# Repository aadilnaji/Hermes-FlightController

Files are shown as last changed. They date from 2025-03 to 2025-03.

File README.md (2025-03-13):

# **Hermes Flight Controller**

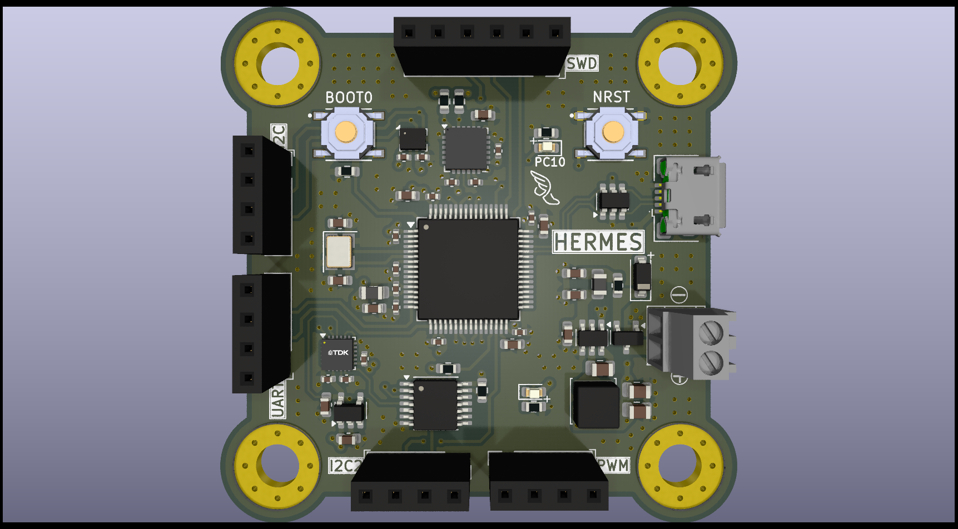
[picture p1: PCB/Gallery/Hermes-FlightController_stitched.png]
Project Banner


## **Overview**
This is a **custom STM32F405 based Flight Controller** designed for drone applications. The PCB is designed in **KiCad**.

Design is done and now it's onto fabricating the PCB and writing the firmware.
Check back for updates.

## **Features**
- **Microcontroller:** STM32F405RGT6
- **IMU Sensor:** MPU-6050 / ICM-2098
- **Barometer:** BMP280
- **ESC Outputs:** 4x PWM channels
- **Communication Interfaces:** UART, I2C, USB

## **Hardware Design**
### **Schematic & PCB Layout**
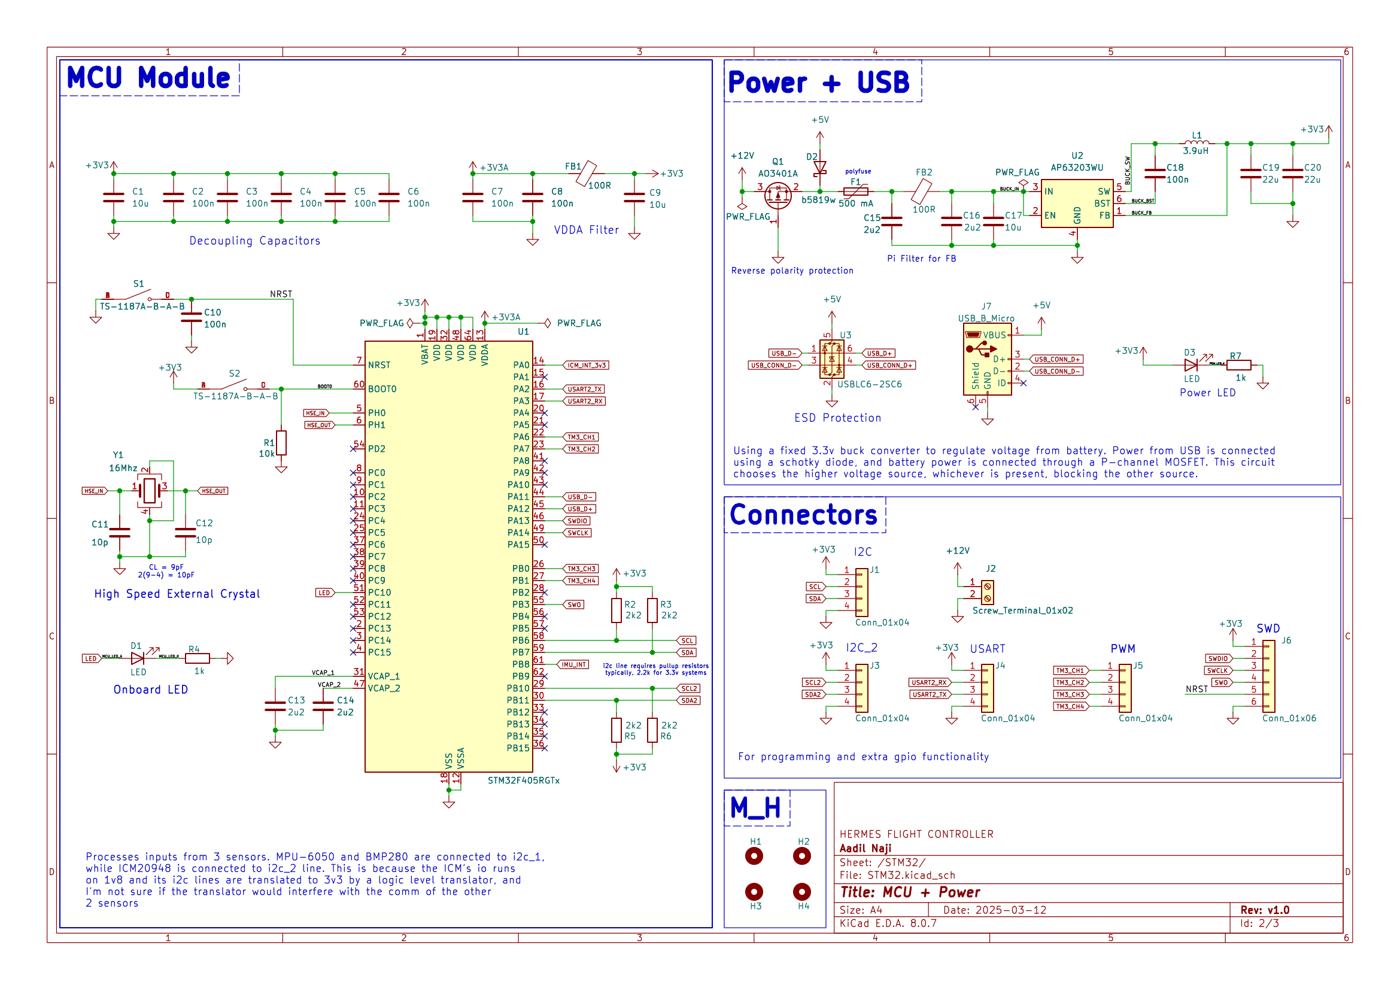
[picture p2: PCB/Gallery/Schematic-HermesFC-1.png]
Schematic1

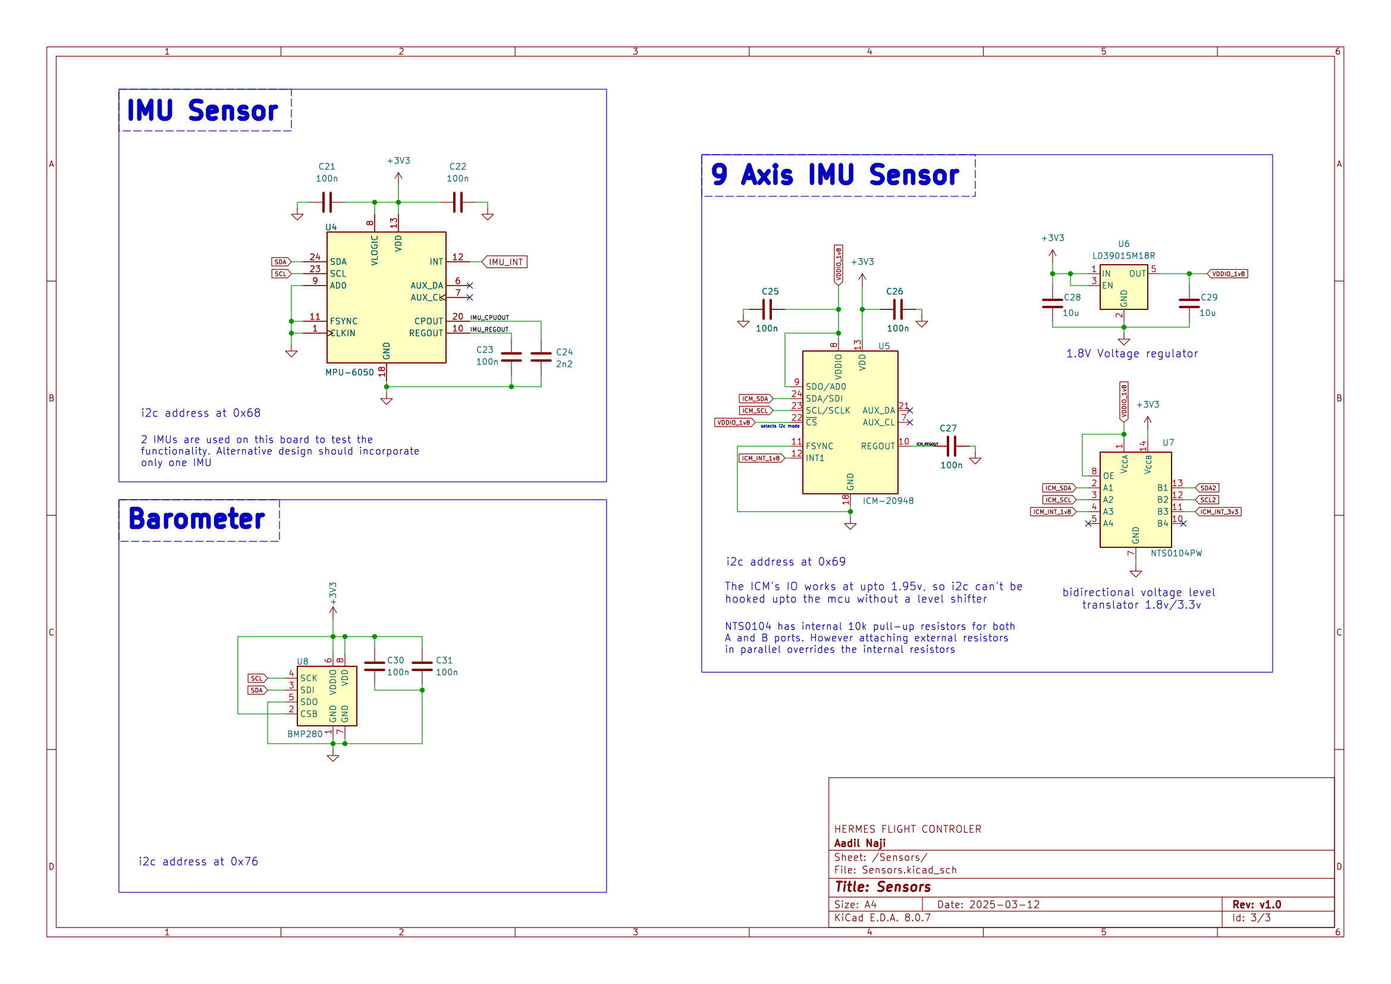
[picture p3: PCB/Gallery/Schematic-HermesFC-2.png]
Schematic2

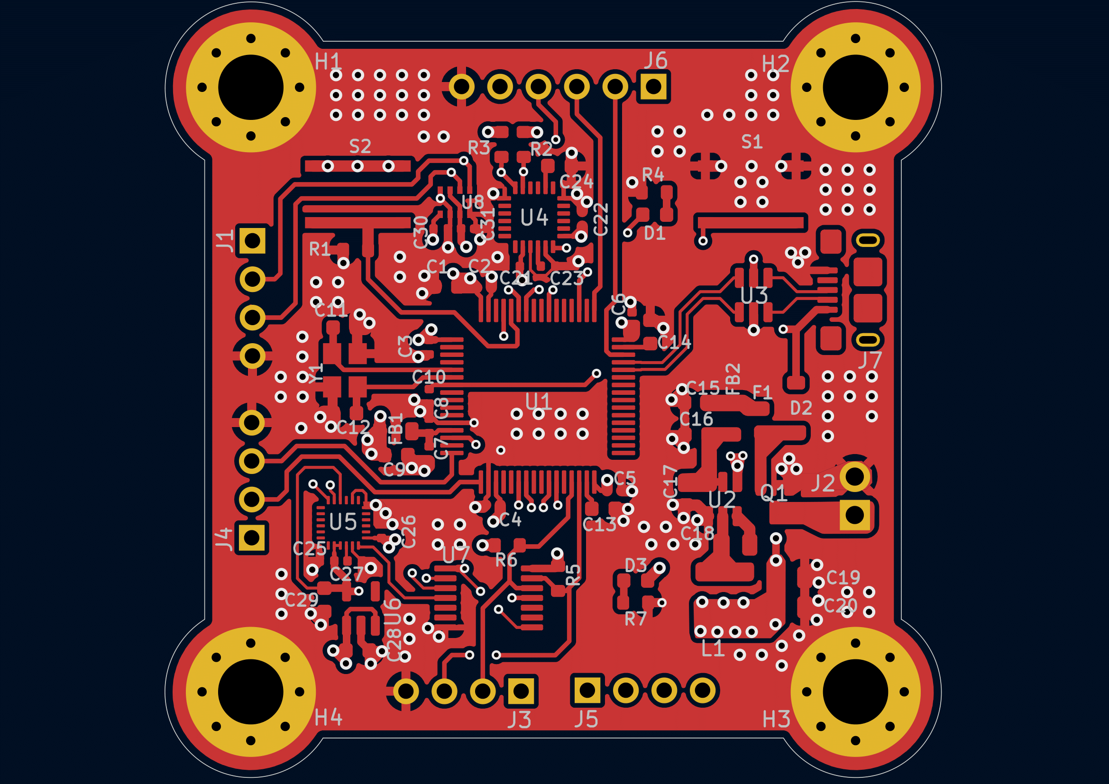
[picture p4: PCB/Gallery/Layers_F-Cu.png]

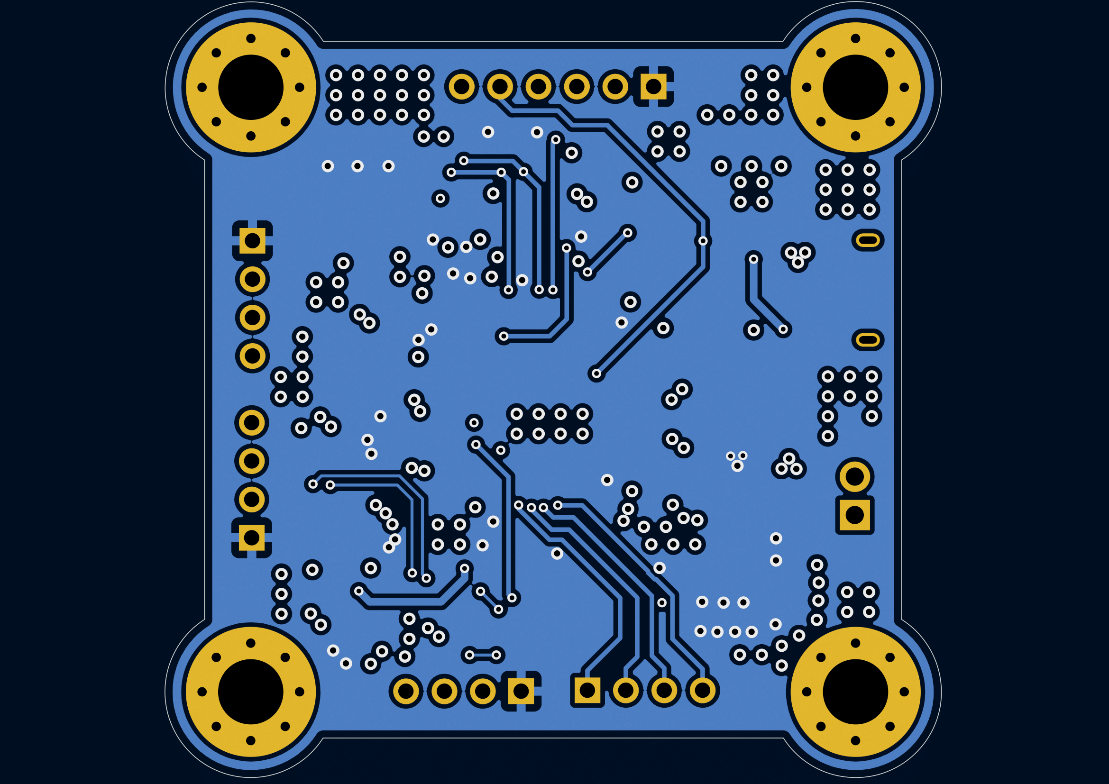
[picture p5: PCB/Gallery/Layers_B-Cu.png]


## **License**
This project is open-source under the **MIT License**.

---
🚀 **Happy Flying!**

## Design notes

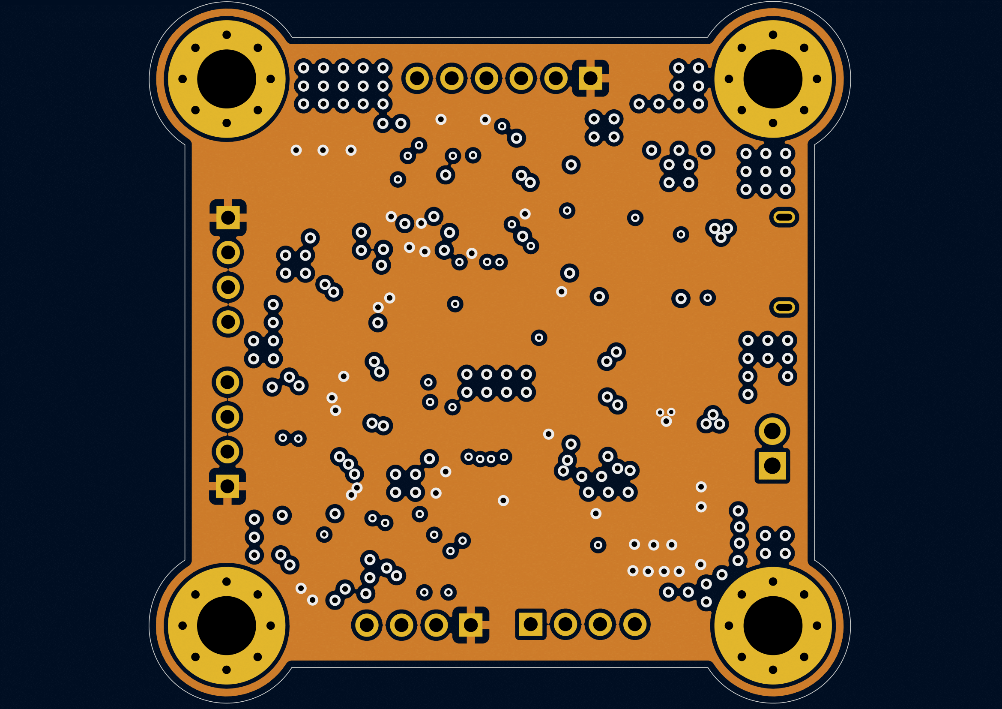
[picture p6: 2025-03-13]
PCB/Gallery/Layers_ln2.png

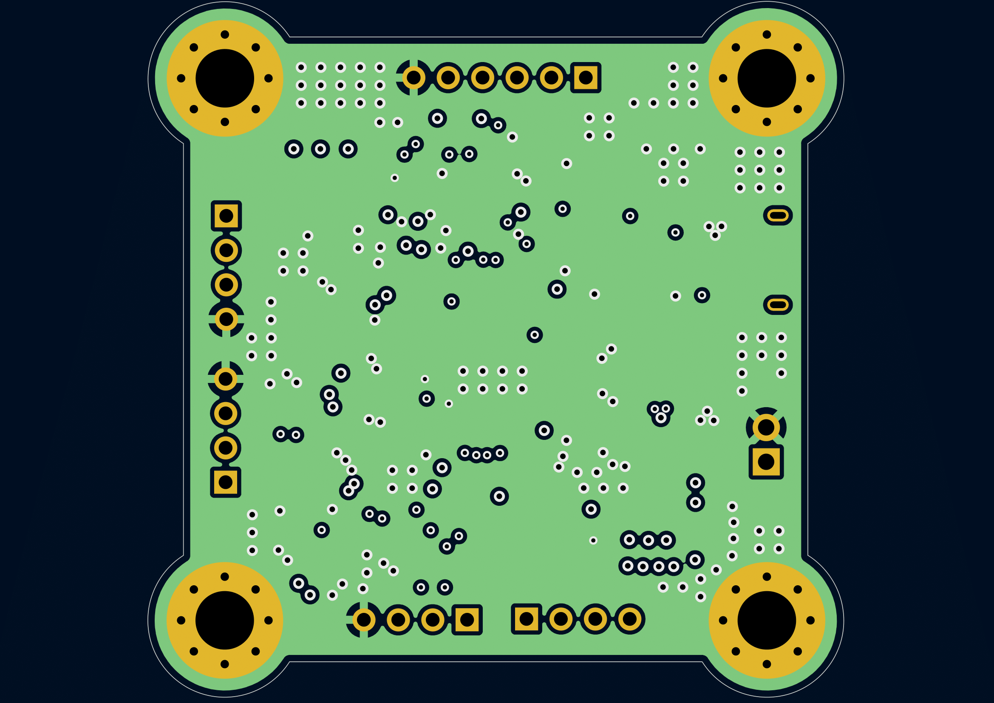
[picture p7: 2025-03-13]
PCB/Gallery/Layers_ln1.png

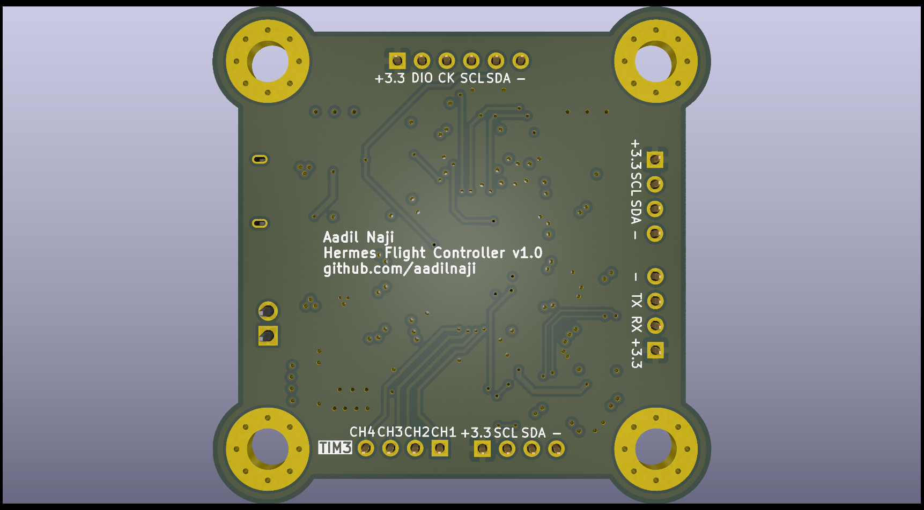
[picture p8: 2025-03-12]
PCB/Gallery/Hermes-FlightController_back.png

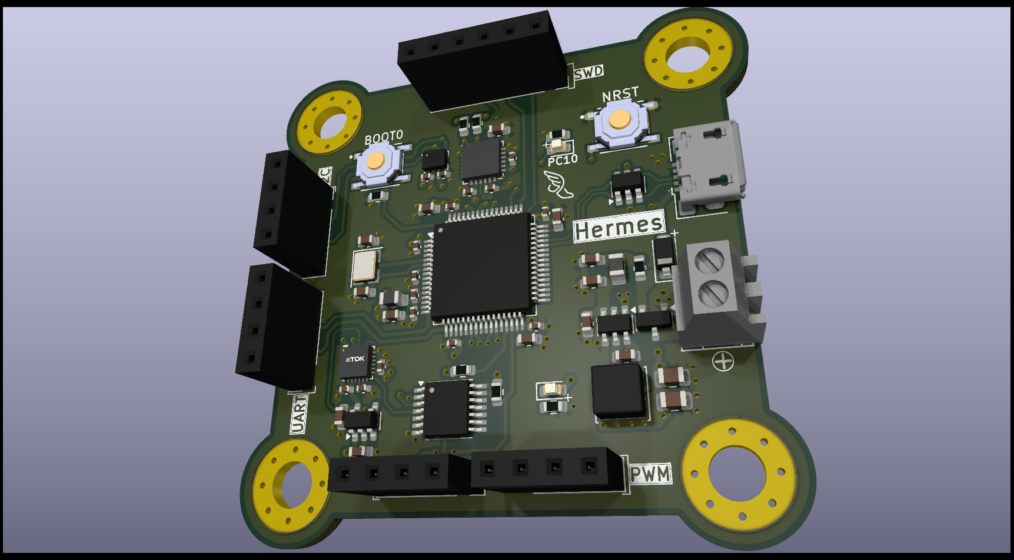
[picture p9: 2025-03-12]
PCB/Gallery/HermesFC_iso.png

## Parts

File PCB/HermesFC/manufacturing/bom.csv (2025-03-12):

Designator | Footprint | Quantity | Value | LCSC Part #
C1, C17, C28, C29, C9 | 603 | 5 | 10u | C96446
C10, C2, C21, C22, C23, C25, C26, C27, C3, C30, C31, C4, C5, C6, C7, C8 | 402 | 16 | 100n | C1525
C11, C12 | 603 | 2 | 10p | C1634
C13, C14, C15, C16 | 603 | 4 | 2u2 | C23630
C18 | 805 | 1 | 100n | C49678
C19, C20 | 805 | 2 | 22u | C45783
C24 | 603 | 1 | 2n2 | C1604
D1, D3 | 603 | 2 | LED | C2286
D2 | D_SOD-123 | 1 | b5819w | C8598
F1 | 603 | 1 | 500 mA | C20798
FB1, FB2 | 805 | 2 | 100R | C1015
L1 | L_Sunlord_SWPA4030S | 1 | 3.9uH | C96899
Q1 | SOT-23 | 1 | AO3401A | C15127
R1 | 603 | 1 | 10k | C25804
R2, R3, R5, R6 | 603 | 4 | 2k2 | C4190
R4, R7 | 603 | 2 | 1k | C21190
S1, S2 | SW_TS-1187A-B-A-B | 2 | TS-1187A-B-A-B | C318884
U1 | LQFP-64_10x10mm_P0.5mm | 1 | STM32F405RGTx | C15742
U2 | TSOT-23-6 | 1 | AP63203WU | C780769
U3 | SOT-23-6 | 1 | USBLC6-2SC6 | C7519
U4 | InvenSense_QFN-24_4x4mm_P0.5mm | 1 | MPU-6050 | C24112
U5 | InvenSense_QFN-24_3x3mm_P0.4mm | 1 | ICM-20948 | C726001
U6 | SOT-23-5 | 1 | LD39015M18R | C361025
U7 | TSSOP-14_4.4x5mm_P0.65mm | 1 | NTS0104PW | C2802637
U8 | Bosch_LGA-8_2x2.5mm_P0.65mm_ClockwisePinNumbering | 1 | BMP280 | C83291
Y1 | Crystal_SMD_3225-4Pin_3.2x2.5mm | 1 | 16Mhz | C13738

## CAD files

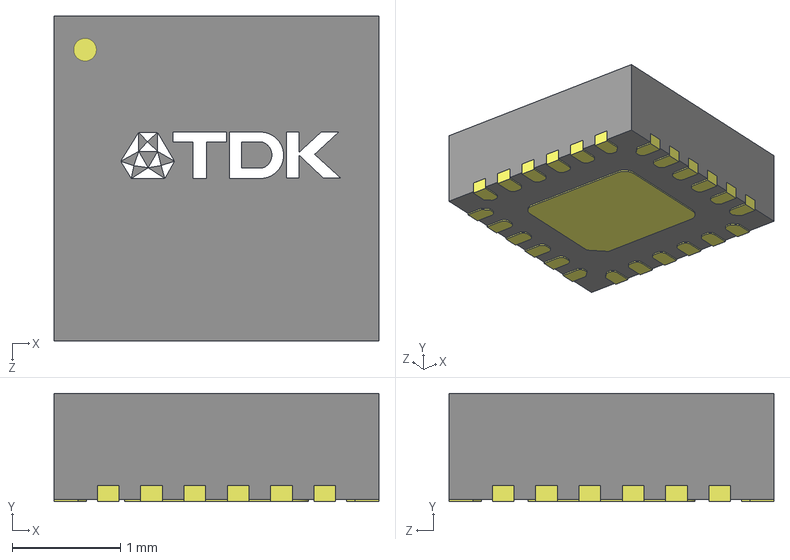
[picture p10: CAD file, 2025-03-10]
PCB/HermesFC/3Dmodels/ICM-20948.stp
3.00 x 1.00 x 3.00 mm

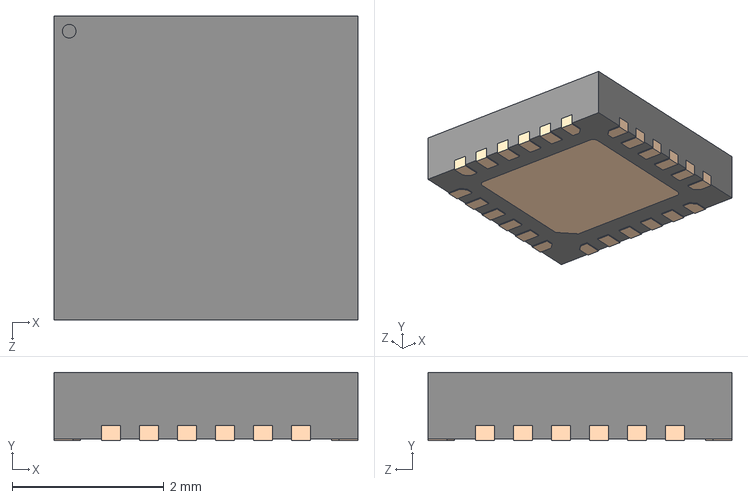
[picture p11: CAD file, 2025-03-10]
PCB/HermesFC/3Dmodels/MPU-6050.stp
4.00 x 0.9 x 4.00 mm

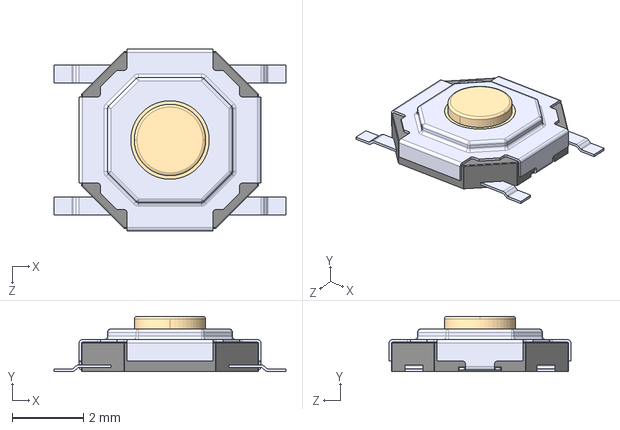
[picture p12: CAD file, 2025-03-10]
PCB/HermesFC/3Dmodels/TS-1187A-B-A-B.step
6.50 x 1.55 x 5.10 mm

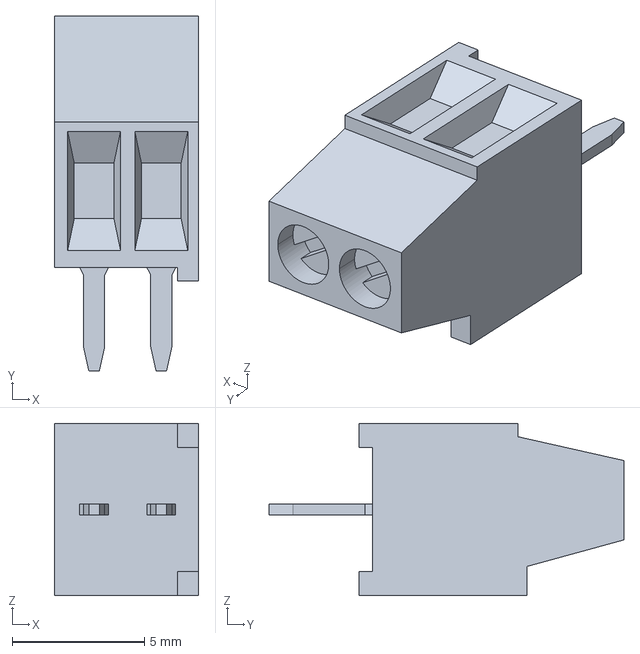
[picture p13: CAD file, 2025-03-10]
PCB/HermesFC/3Dmodels/screwT_2.54.stp
5.45 x 13.4 x 6.50 mm

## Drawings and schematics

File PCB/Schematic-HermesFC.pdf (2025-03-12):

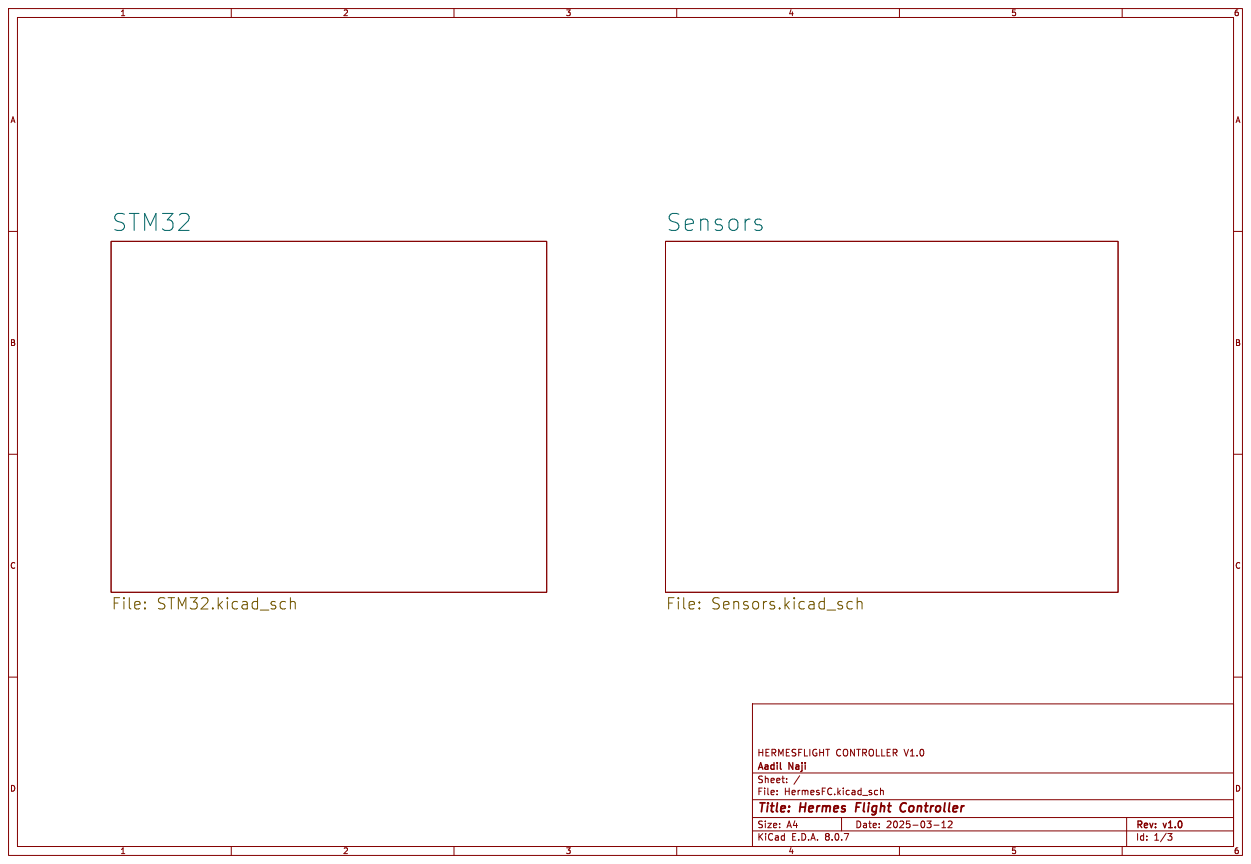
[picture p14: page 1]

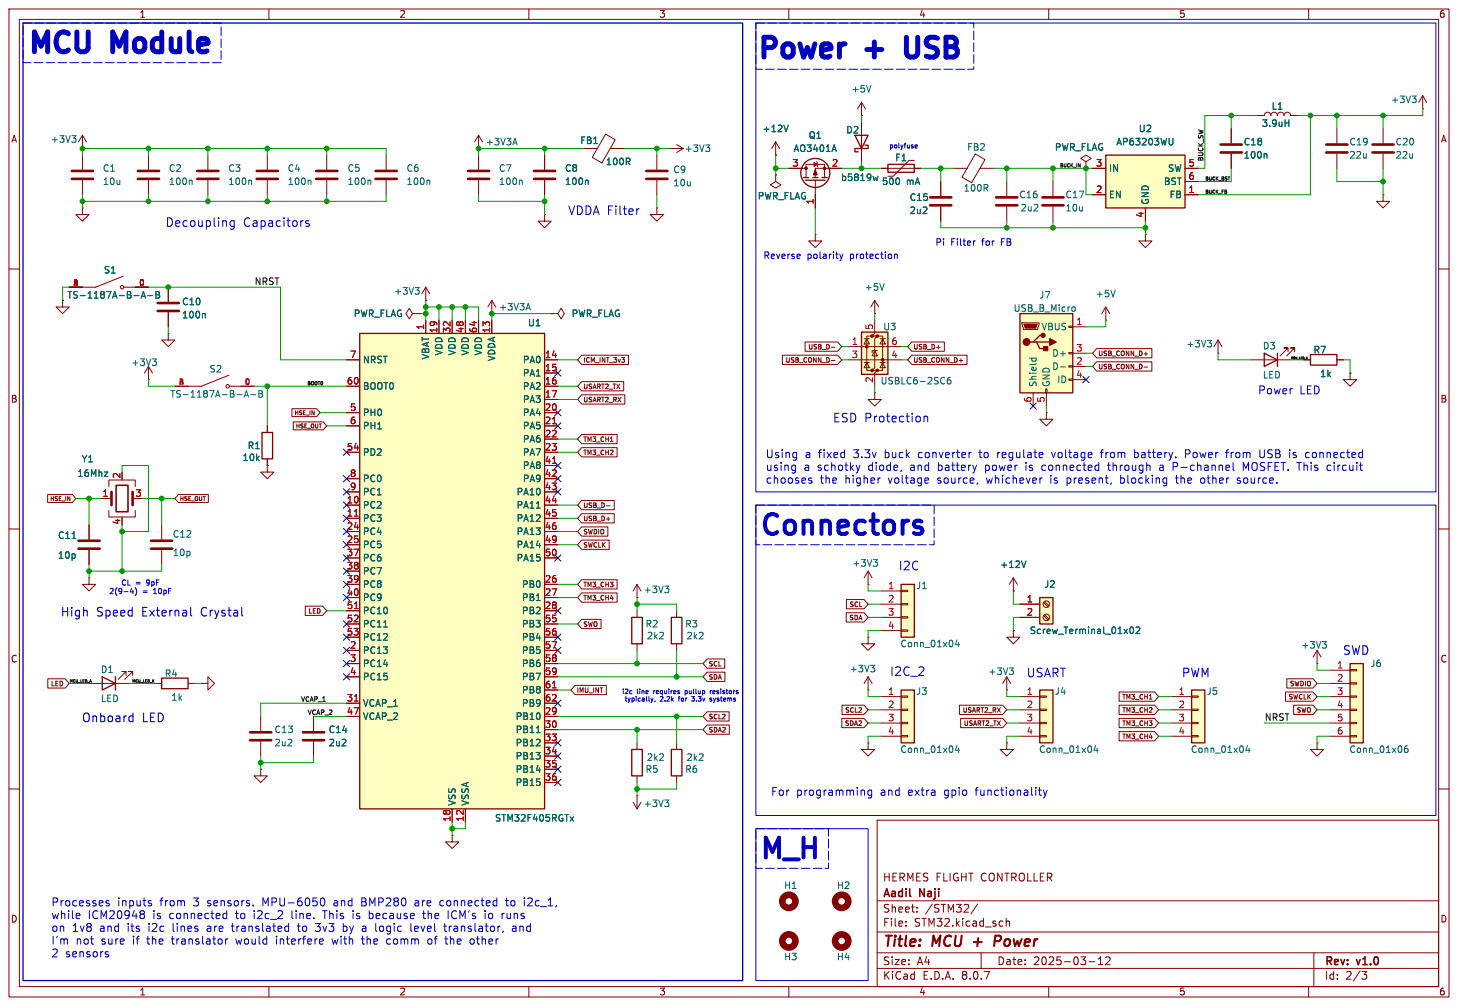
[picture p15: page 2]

1 PC2 10 PC3 11 VSSA 12 VDDA 13 PA0 14 PA1 15 PA2 16 PA3 17 VSS 18 VDD 19 PC13 2 PA4 20 PA5 21 PA6 22 PA7 23 PC4 24 PC5 25 PB0 26 PB1 27 PB2 28 PB10 29 PC14 3 PB11 30 VCAP_1 31 VDD 32 PB12 33 PB13 34 PB14 35 PB15 36 PC6 37 PC7 38 PC8 39 PC15 4 PC9 40 PA8 41 PA9 42 PA10 43 PA11 44 PA12 45 PA13 46 VCAP_2 47 VDD 48 PA14 49 PH0 5 PA15 50 PC10 51 PC11 52 PC12 53 PD2 54 PB3 55 PB4 56 PB5 57 PB6 58 PB7 59 PH1 6 BOOT0 60 PB8 61 PB9 62 VDD 64 NRST 7 PC0 8 PC1 9 C14

1 PC2 10 PC3 11 VSSA 12 VDDA 13 PA0 14 PA1 15 PA2 16 PA3 17 VSS 18 VDD 19 PC13 2 PA4 20 PA5 21 PA6 22 PA7 23 PC4 24 PC5 25 PB0 26 PB1 27 PB2 28 PB10 29 PC14 3 PB11 30 VCAP_1 31 VDD 32 PB12 33 PB13 34 PB14 35 PB15 36 PC6 37 PC7 38 PC8 39 PC15 4 PC9 40 PA8 41 PA9 42 PA10 43 PA11 44 PA12 45 PA13 46 VCAP_2 47 VDD 48 PA14 49 PH0 5 PA15 50 PC10 51 PC11 52 PC12 53 PD2 54 PB3 55 PB4 56 PB5 57 PB6 58 PB7 59 PH1 6 BOOT0 60 PB8 61 PB9 62 VDD 64 NRST 7 PC0 8 PC1 9 U1 STM32F405RGTx R6

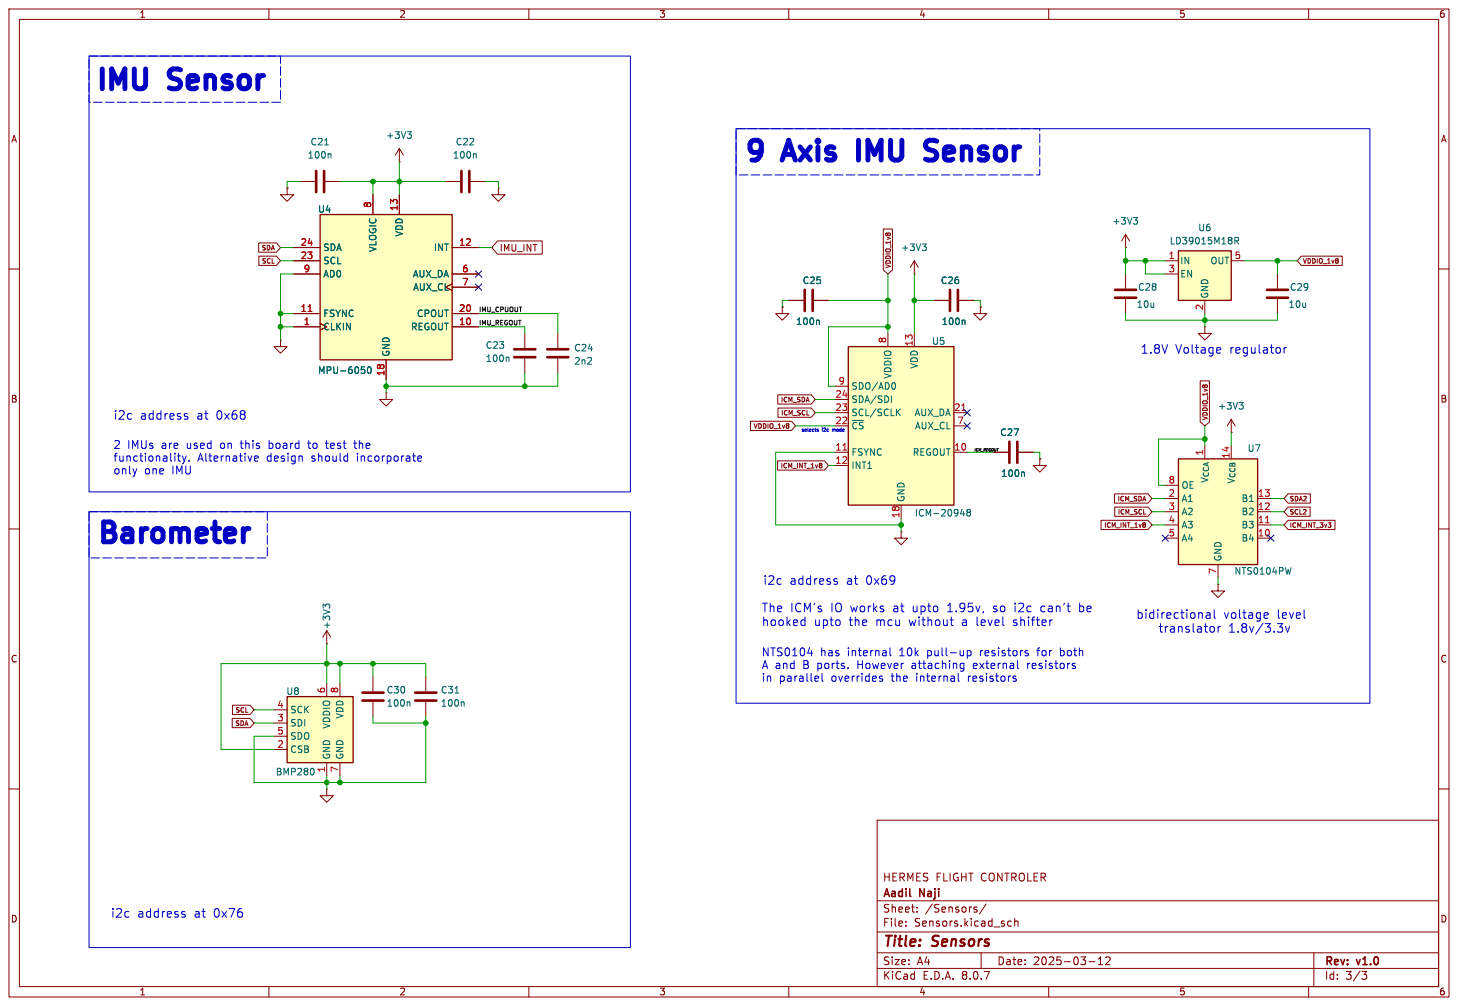
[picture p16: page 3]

2 IMUs are used on this board to test the
only one IMU
Barometer

The ICM's IO works at upto 1.95v, so i2c can't be

1 CSB 2 SDI 3 SCK 4 SDO 5 VDDIO

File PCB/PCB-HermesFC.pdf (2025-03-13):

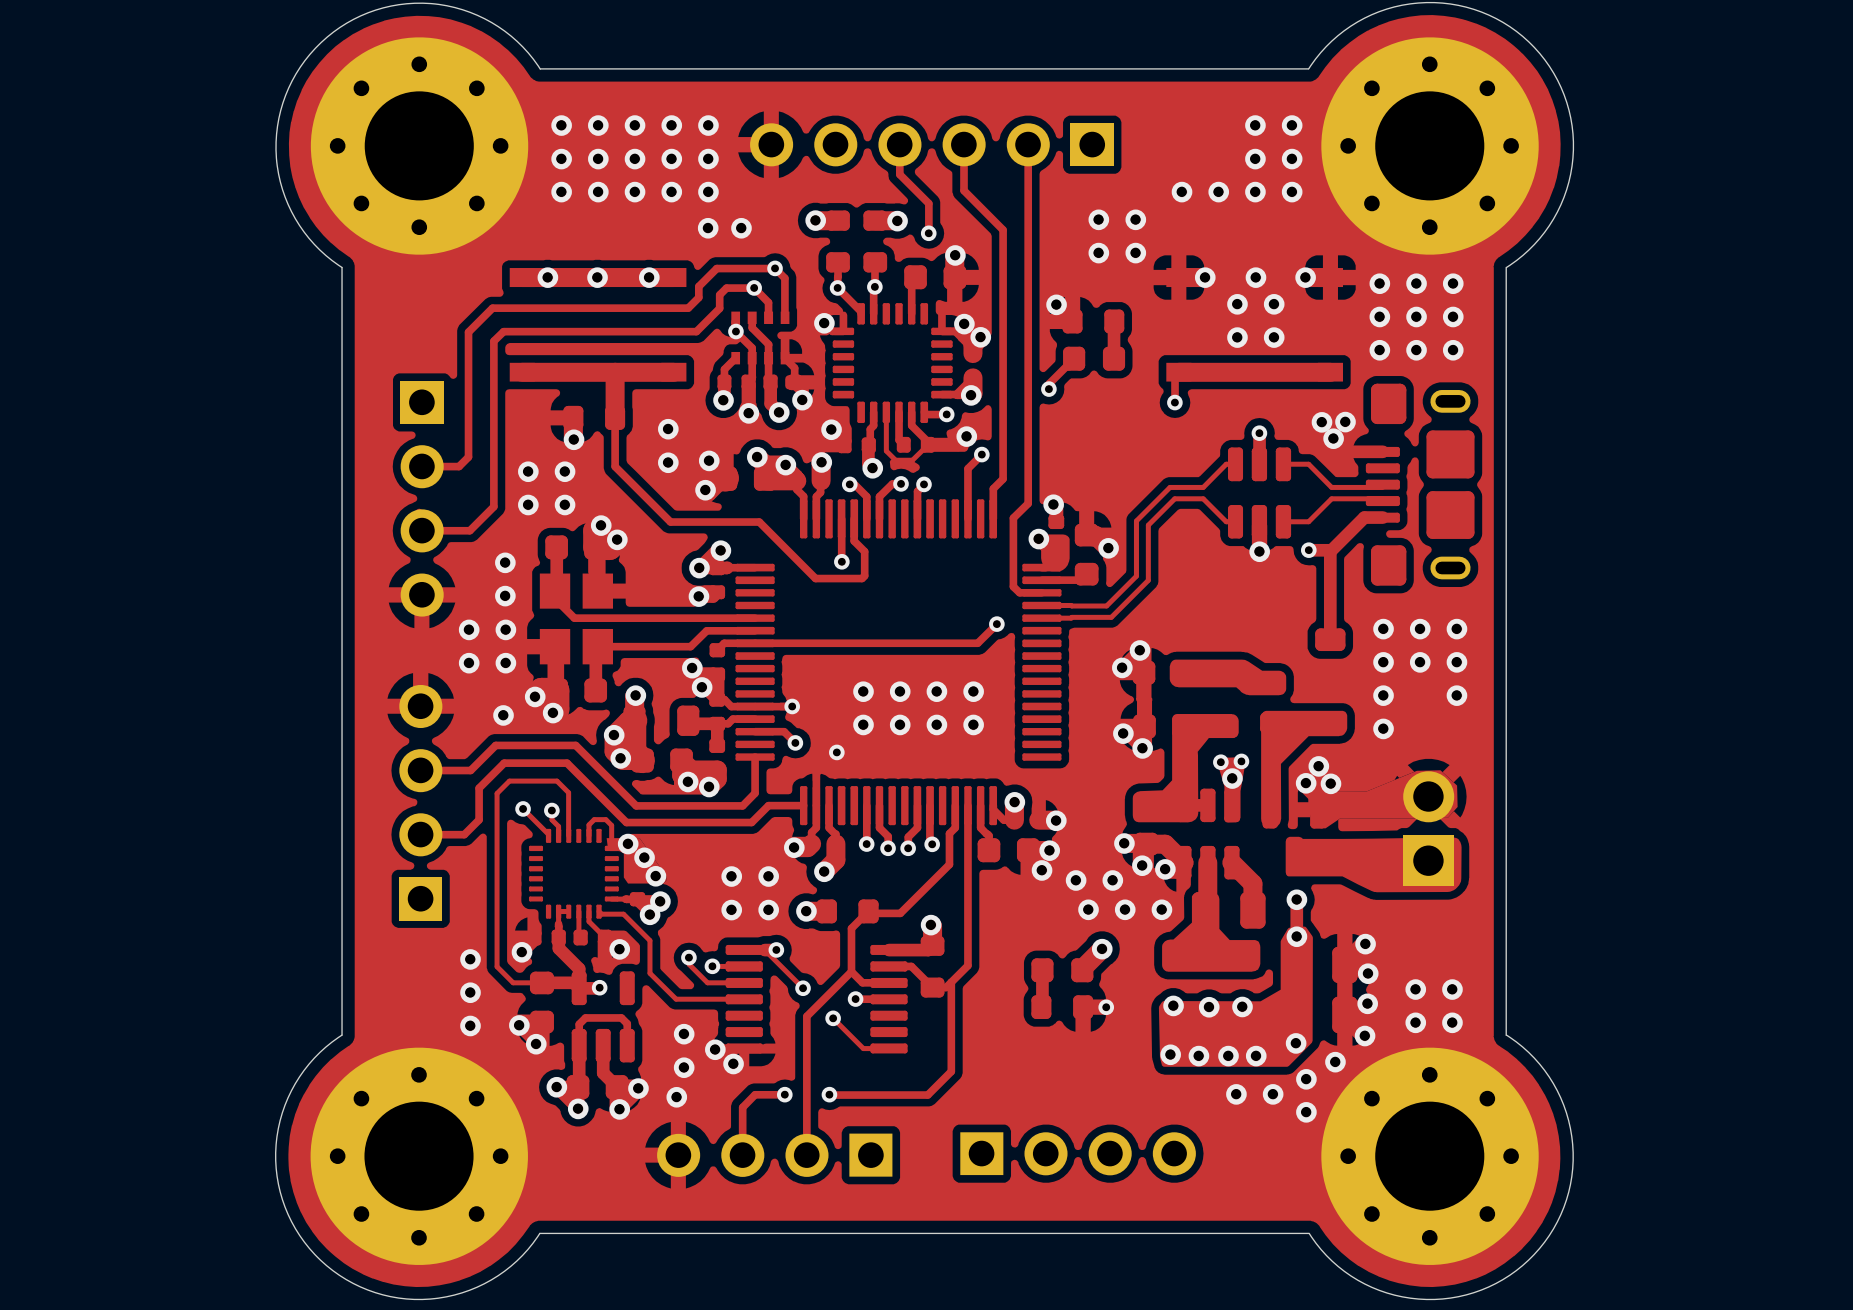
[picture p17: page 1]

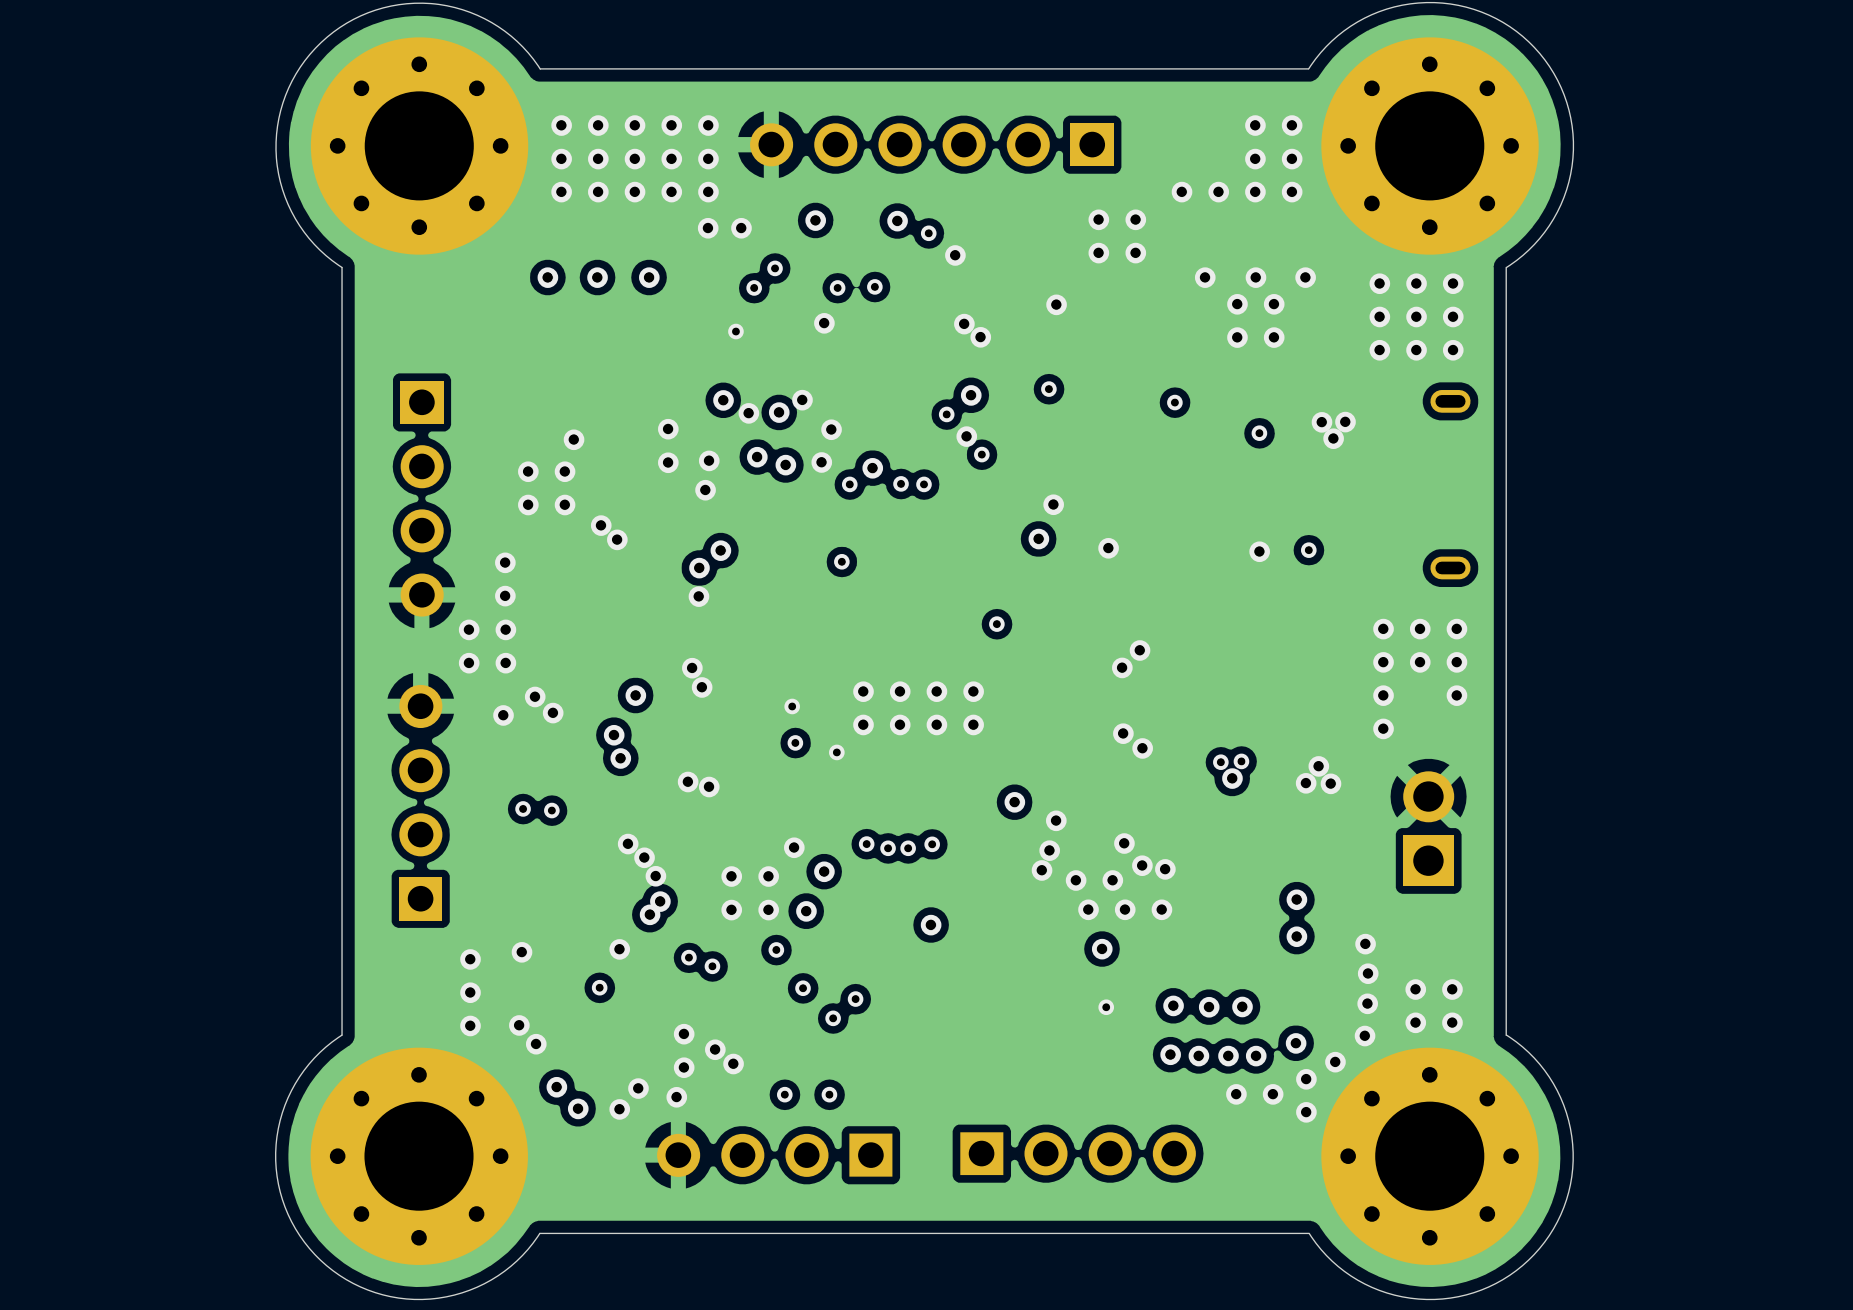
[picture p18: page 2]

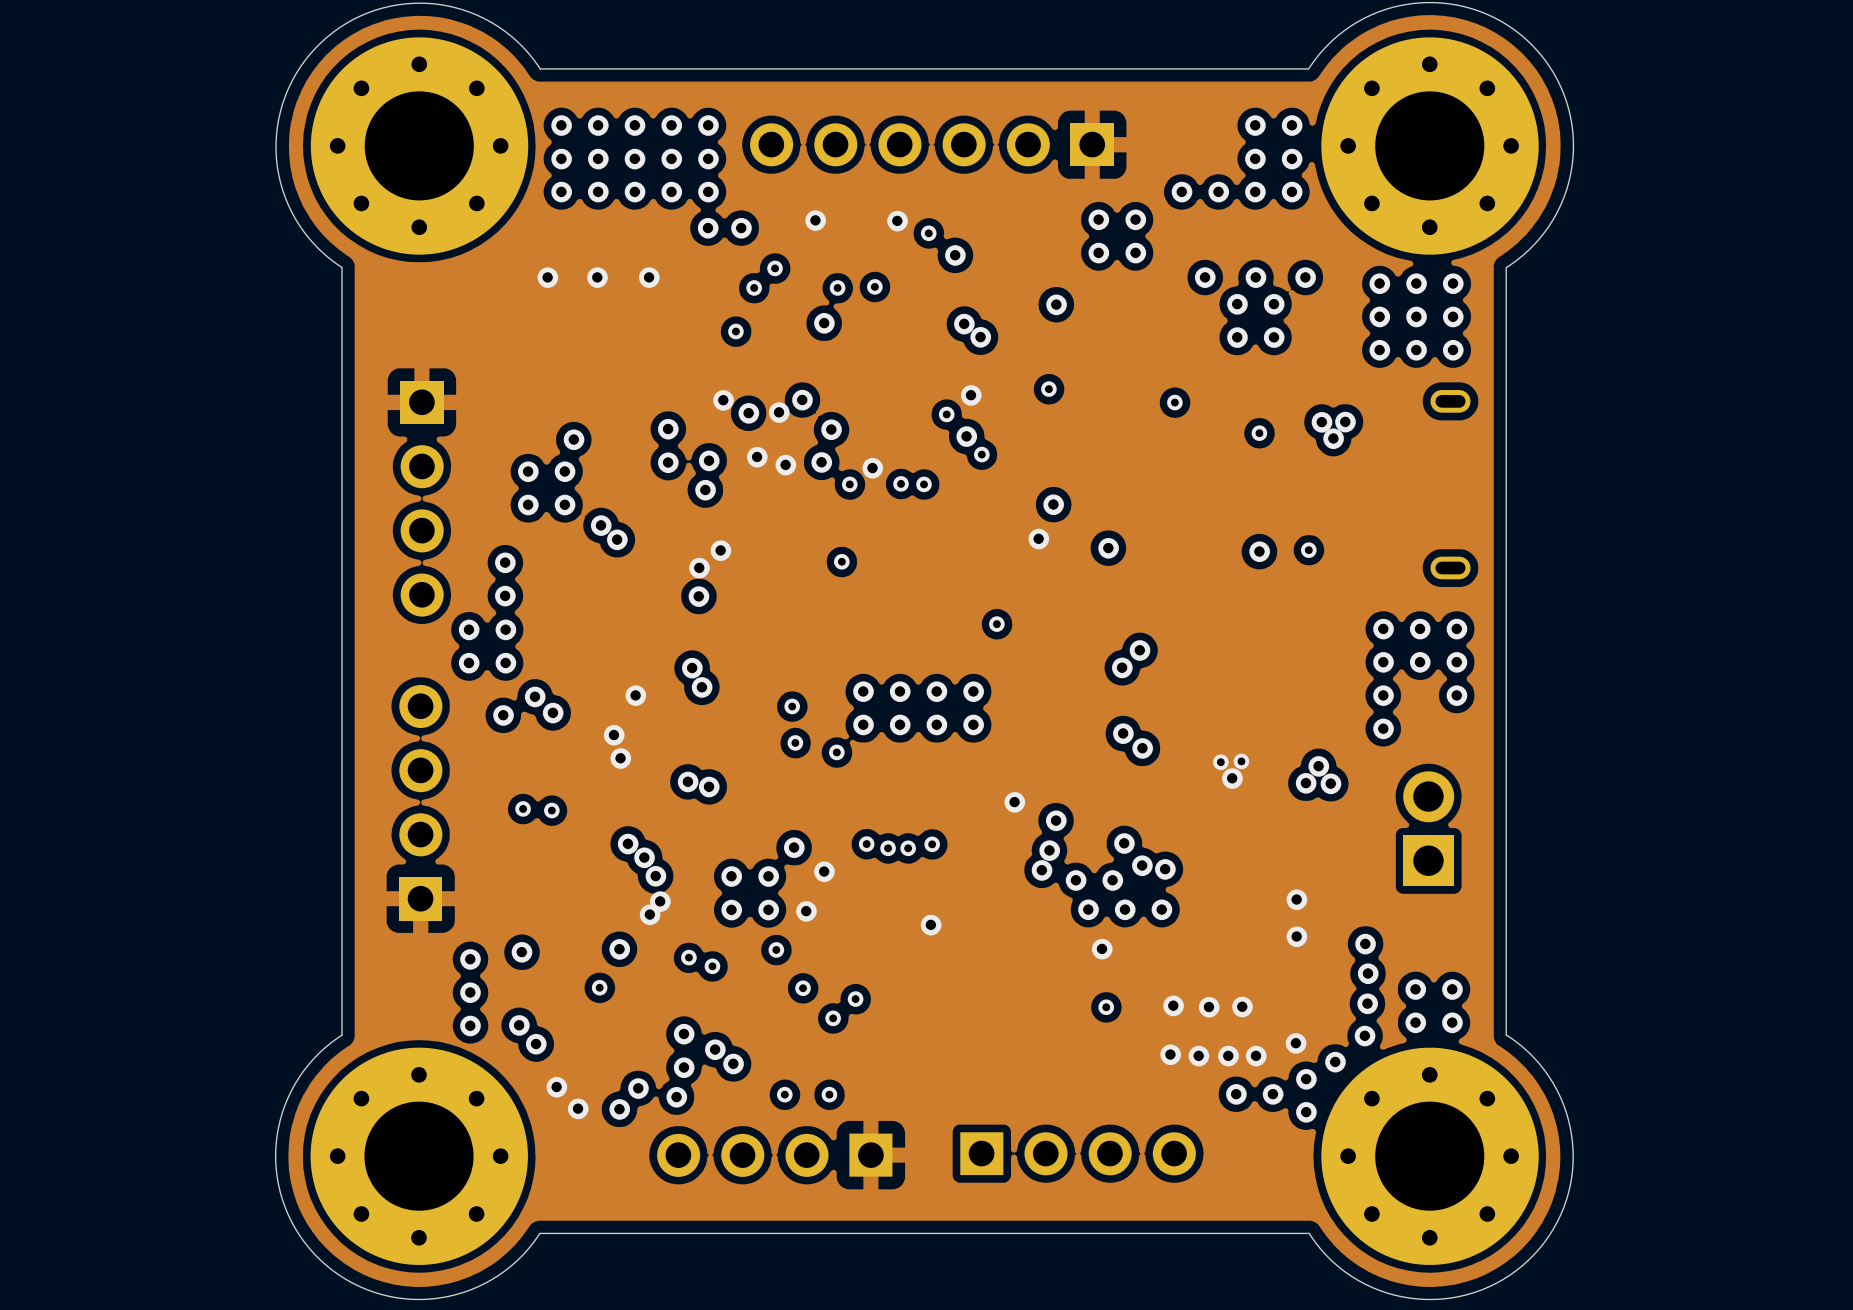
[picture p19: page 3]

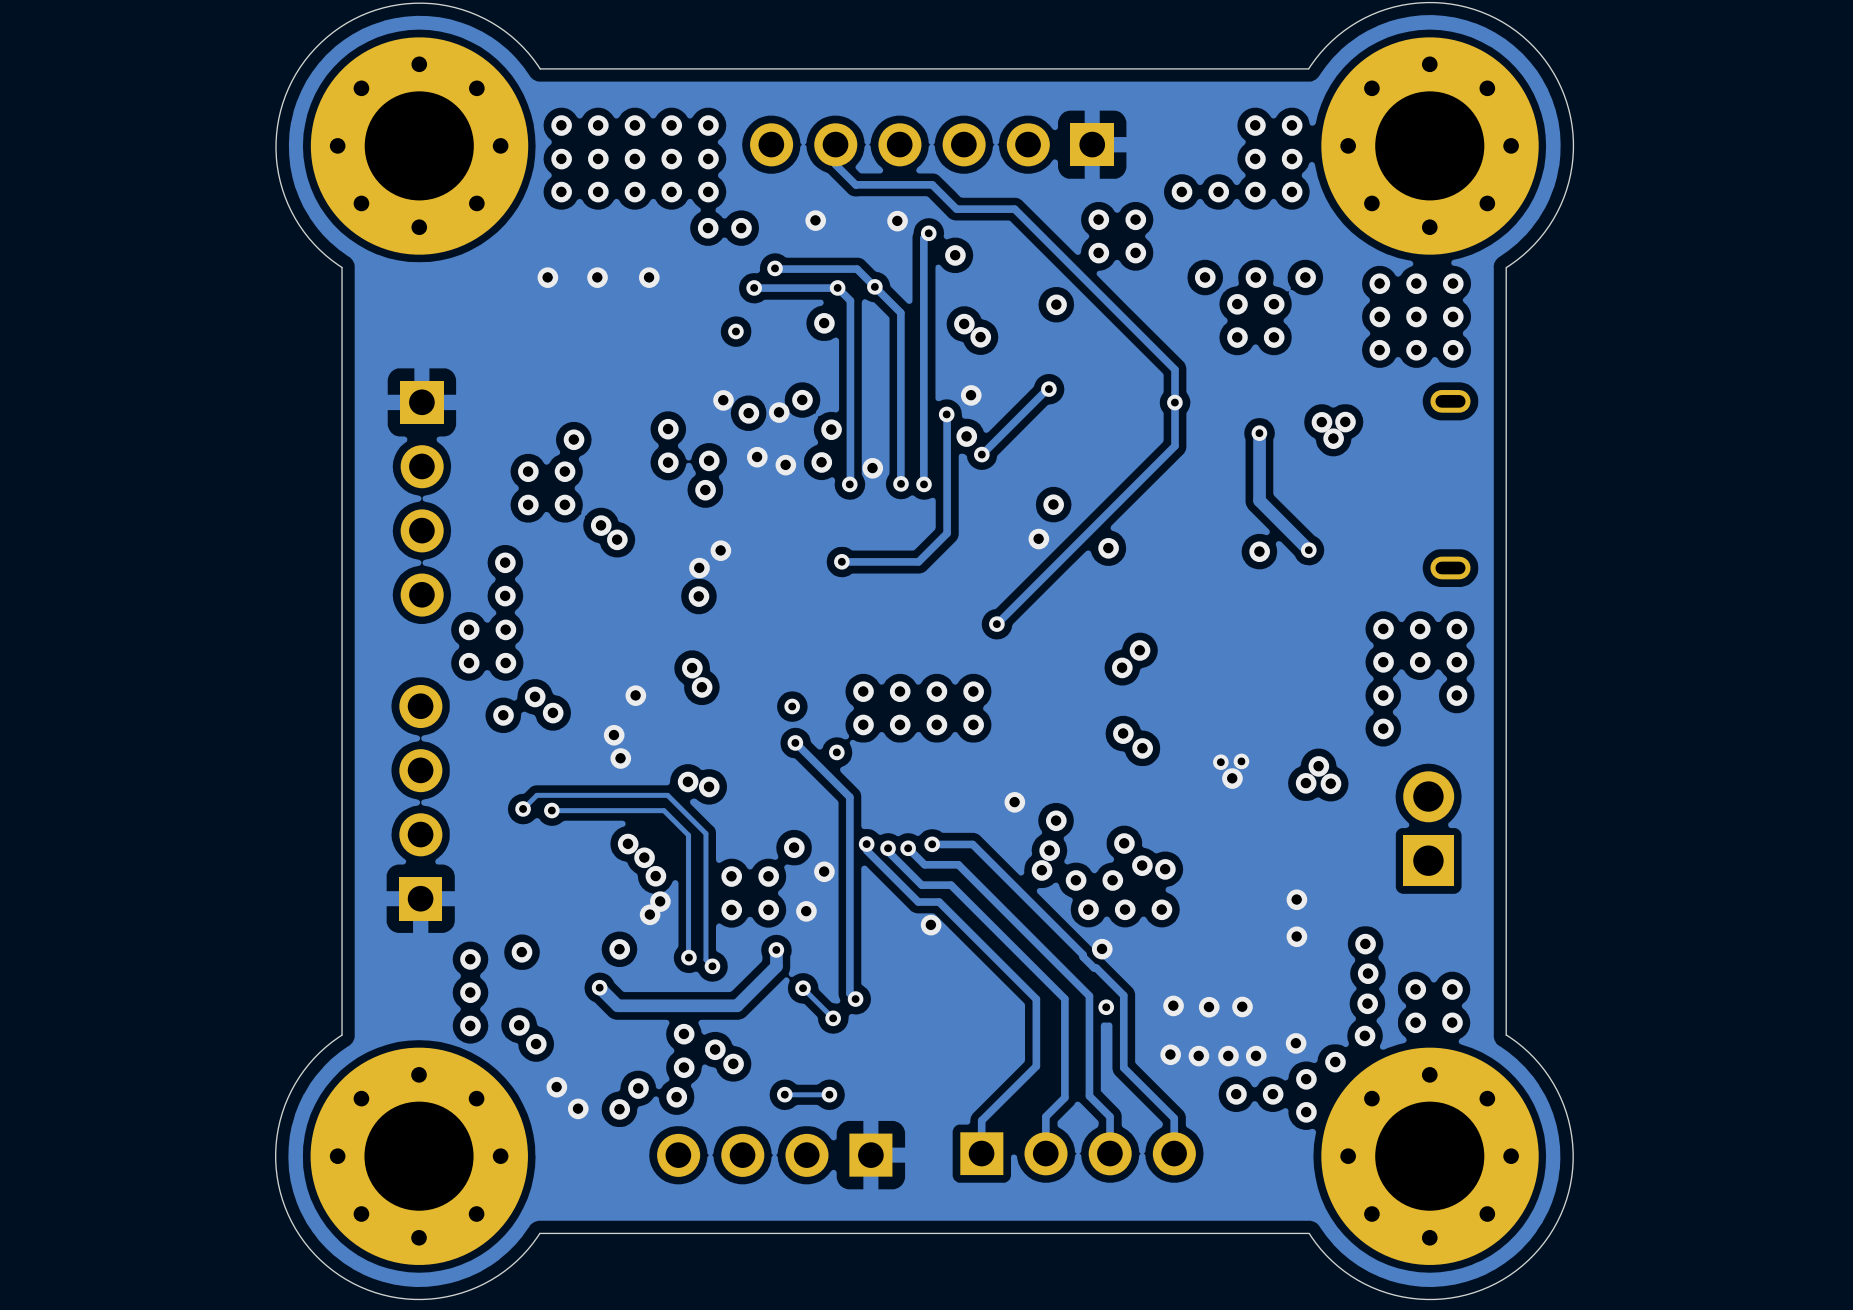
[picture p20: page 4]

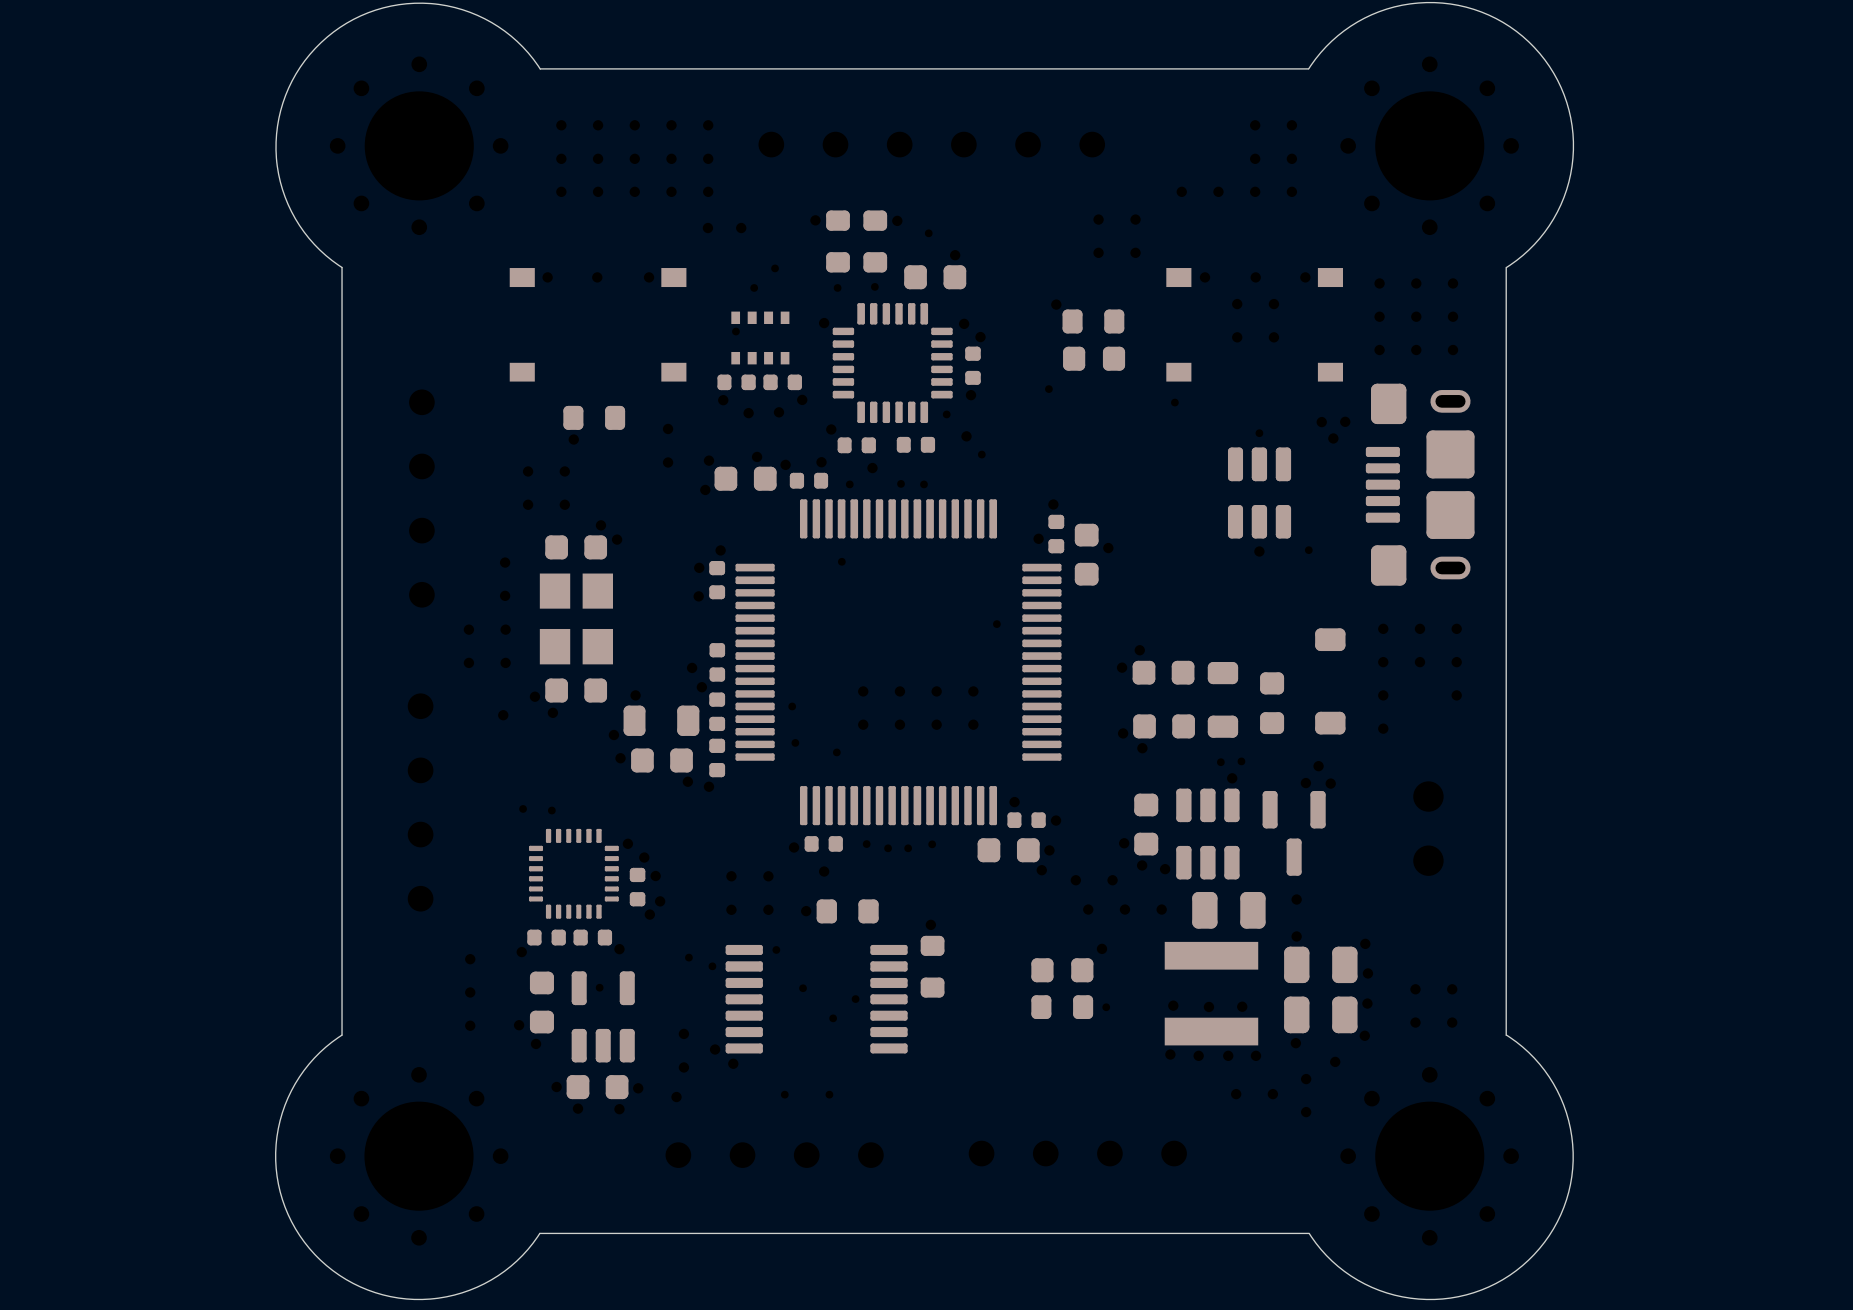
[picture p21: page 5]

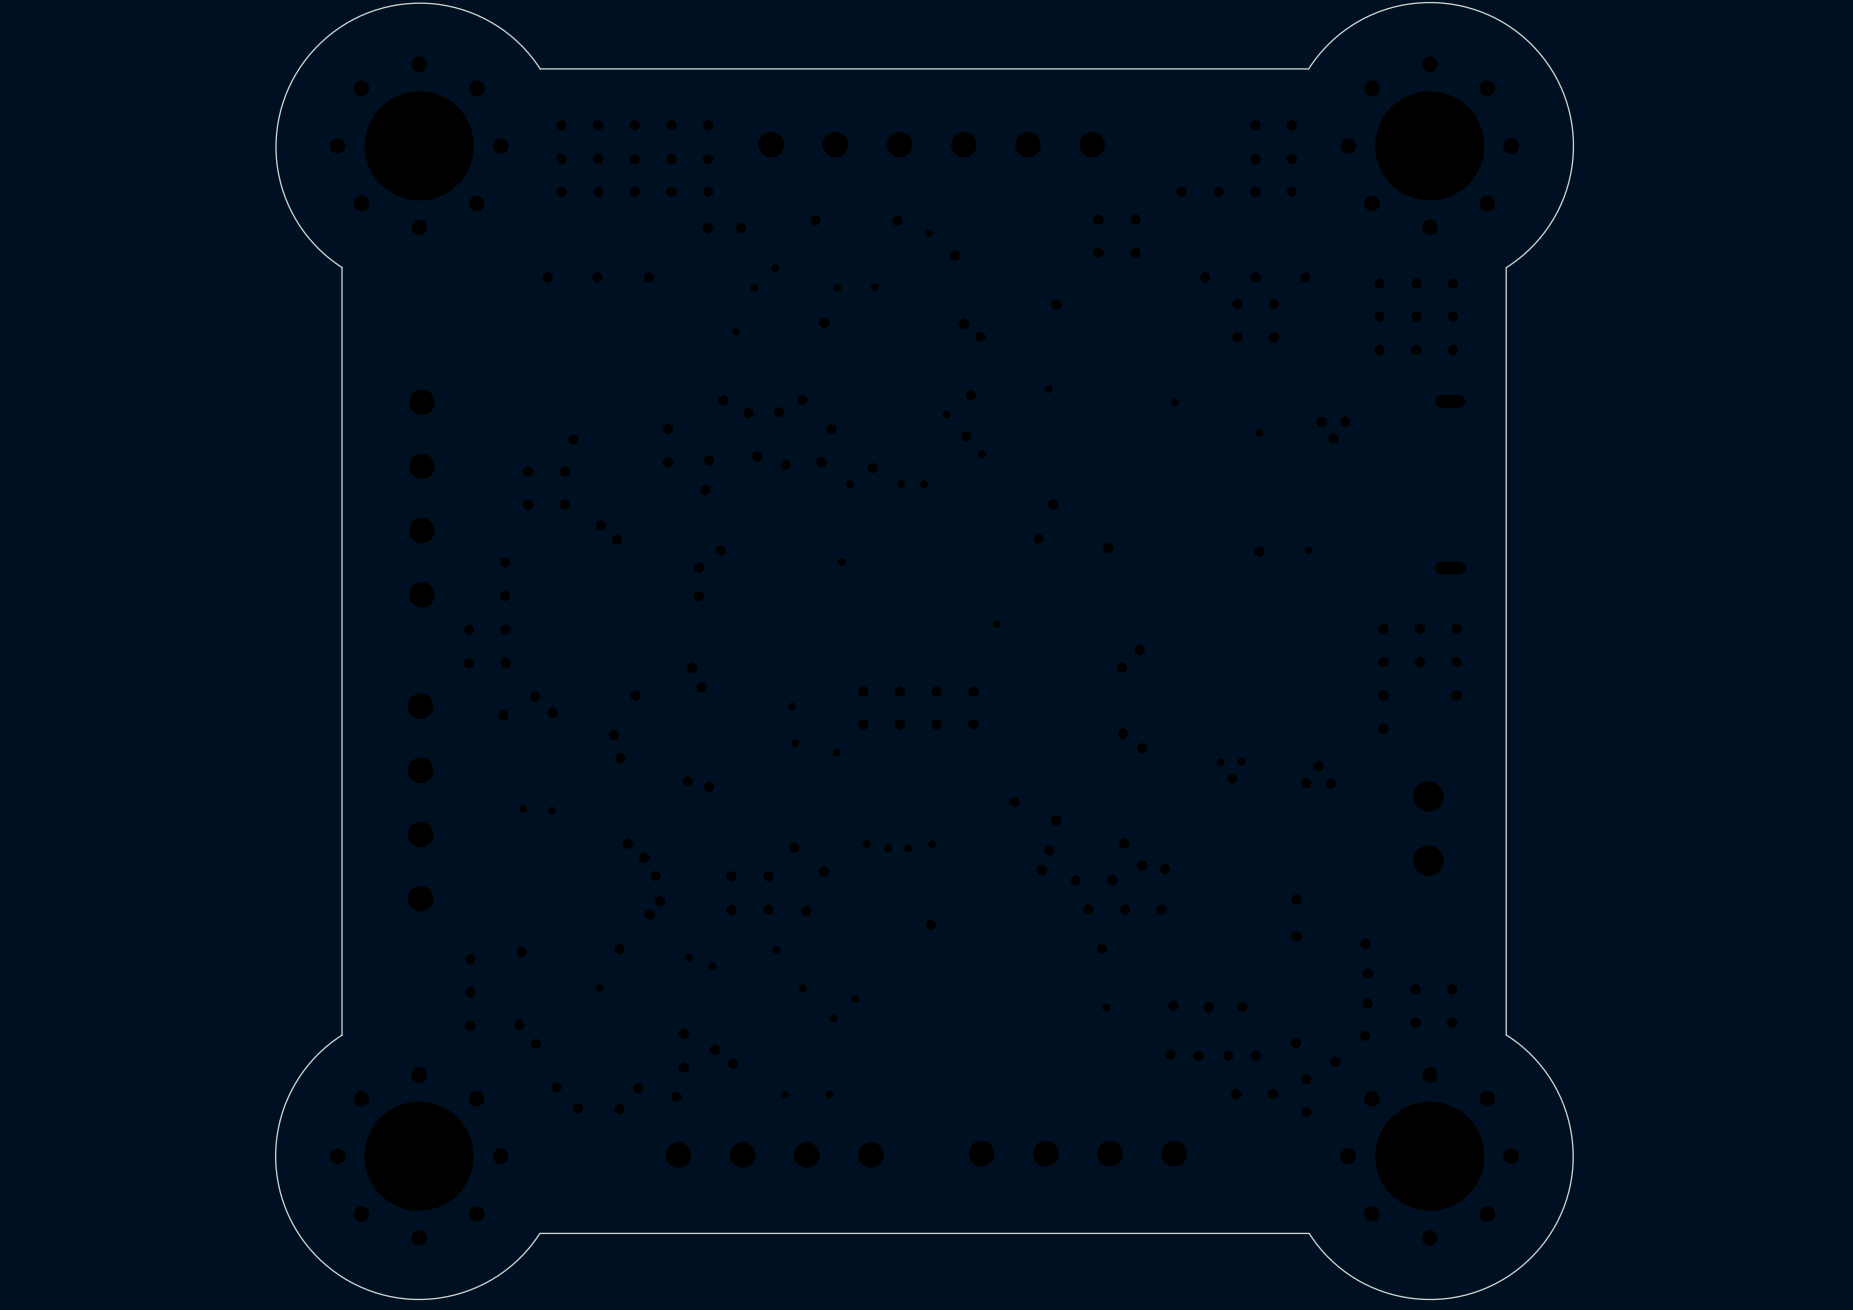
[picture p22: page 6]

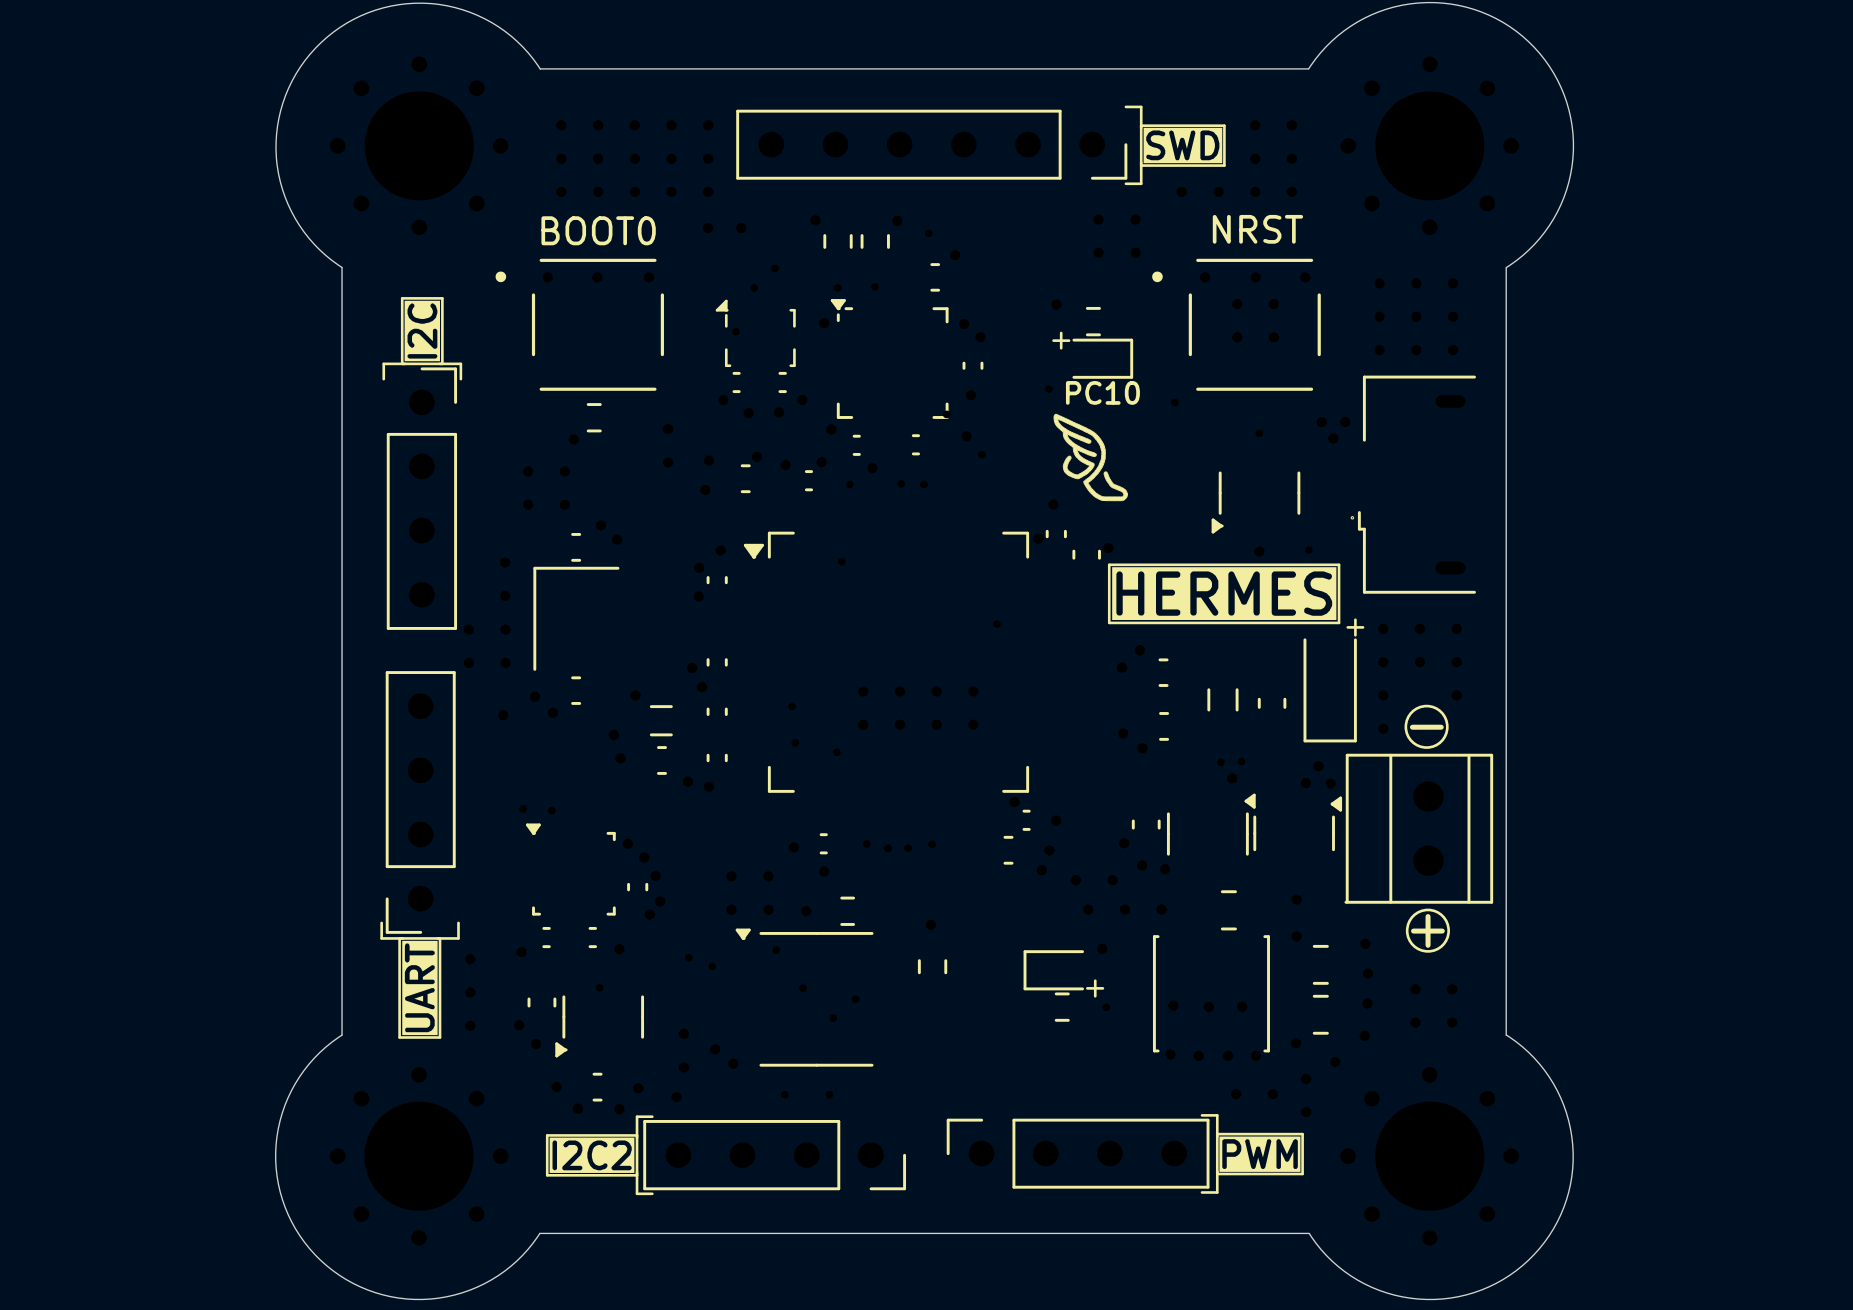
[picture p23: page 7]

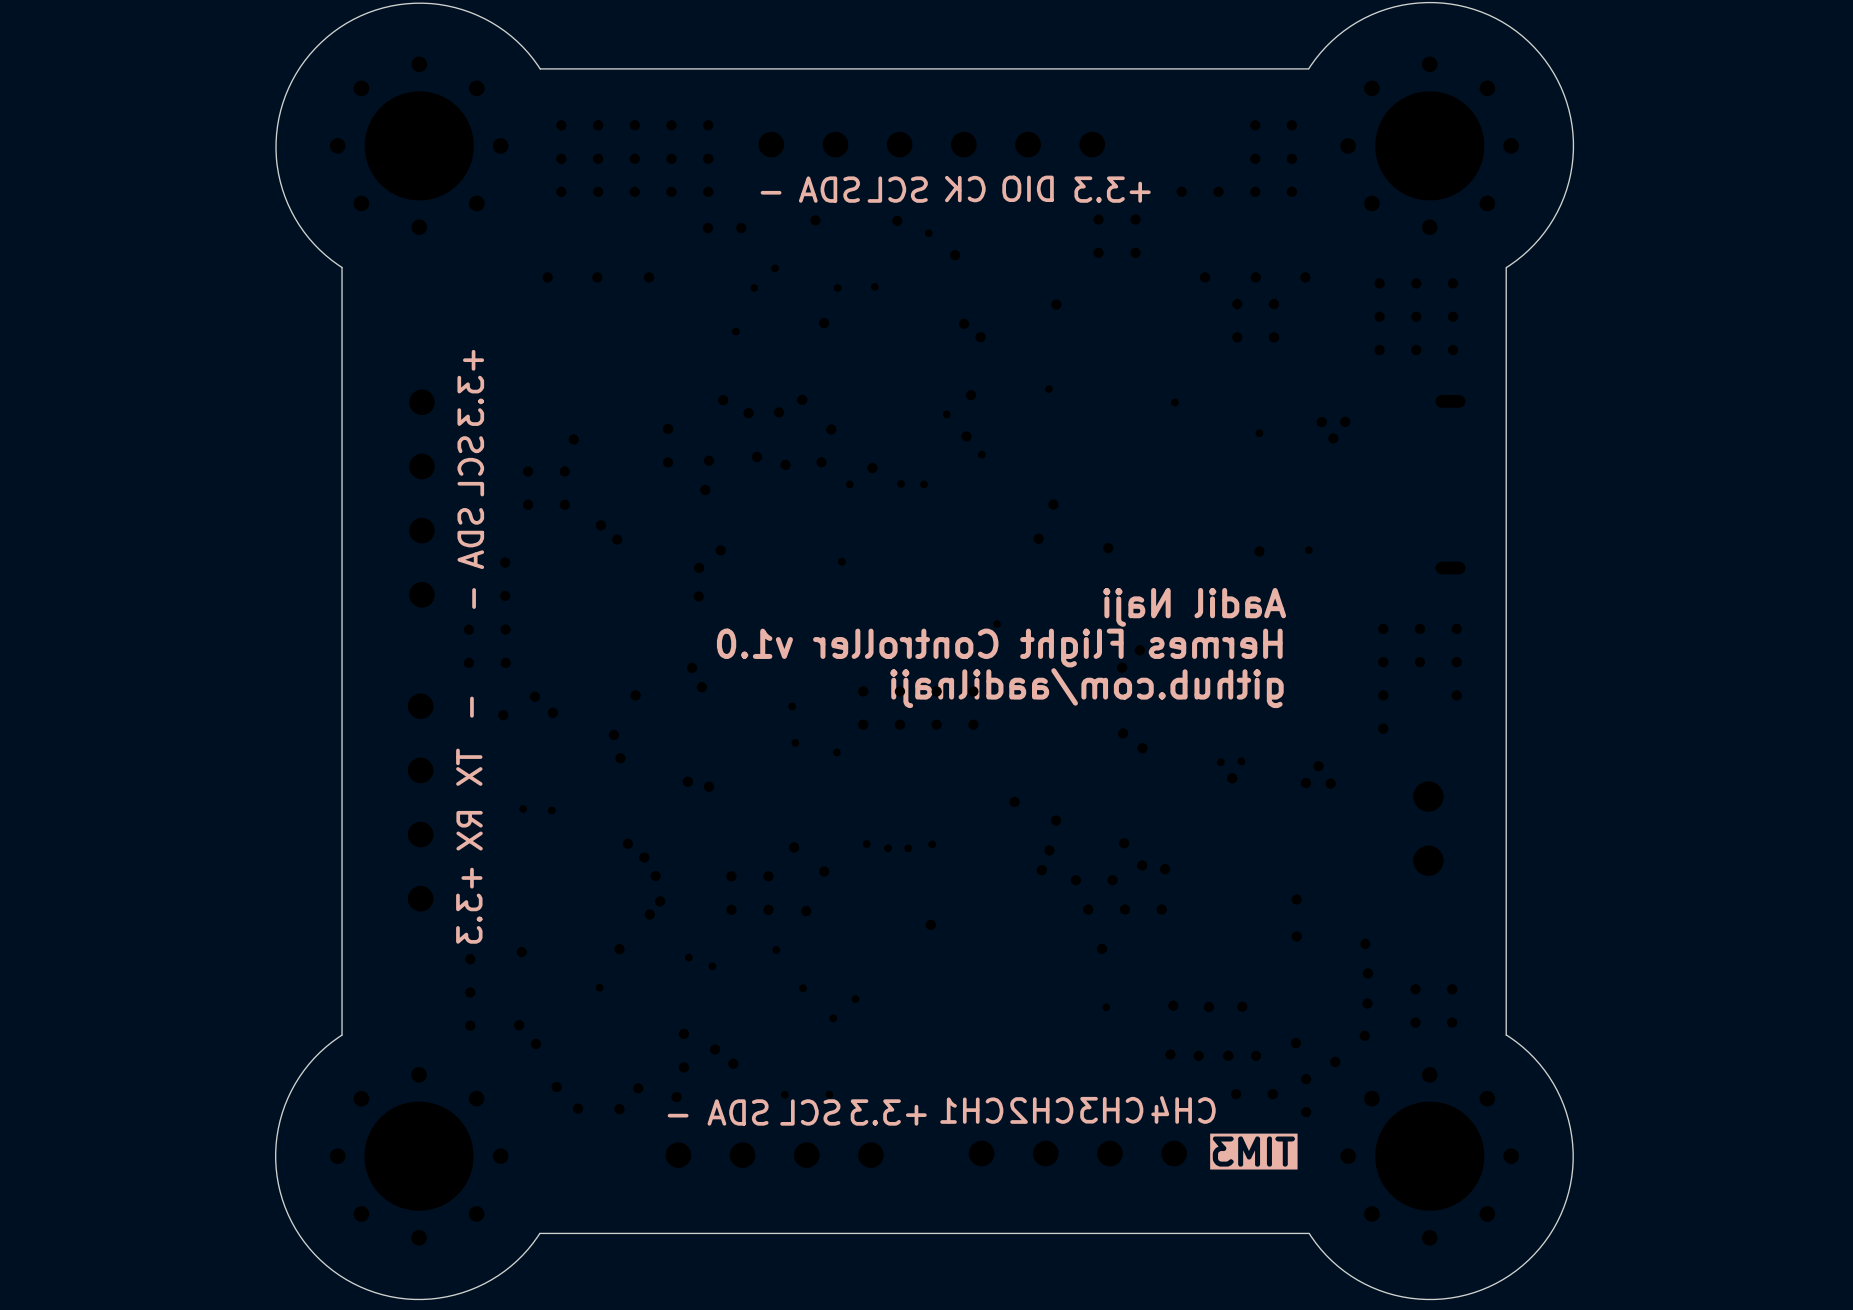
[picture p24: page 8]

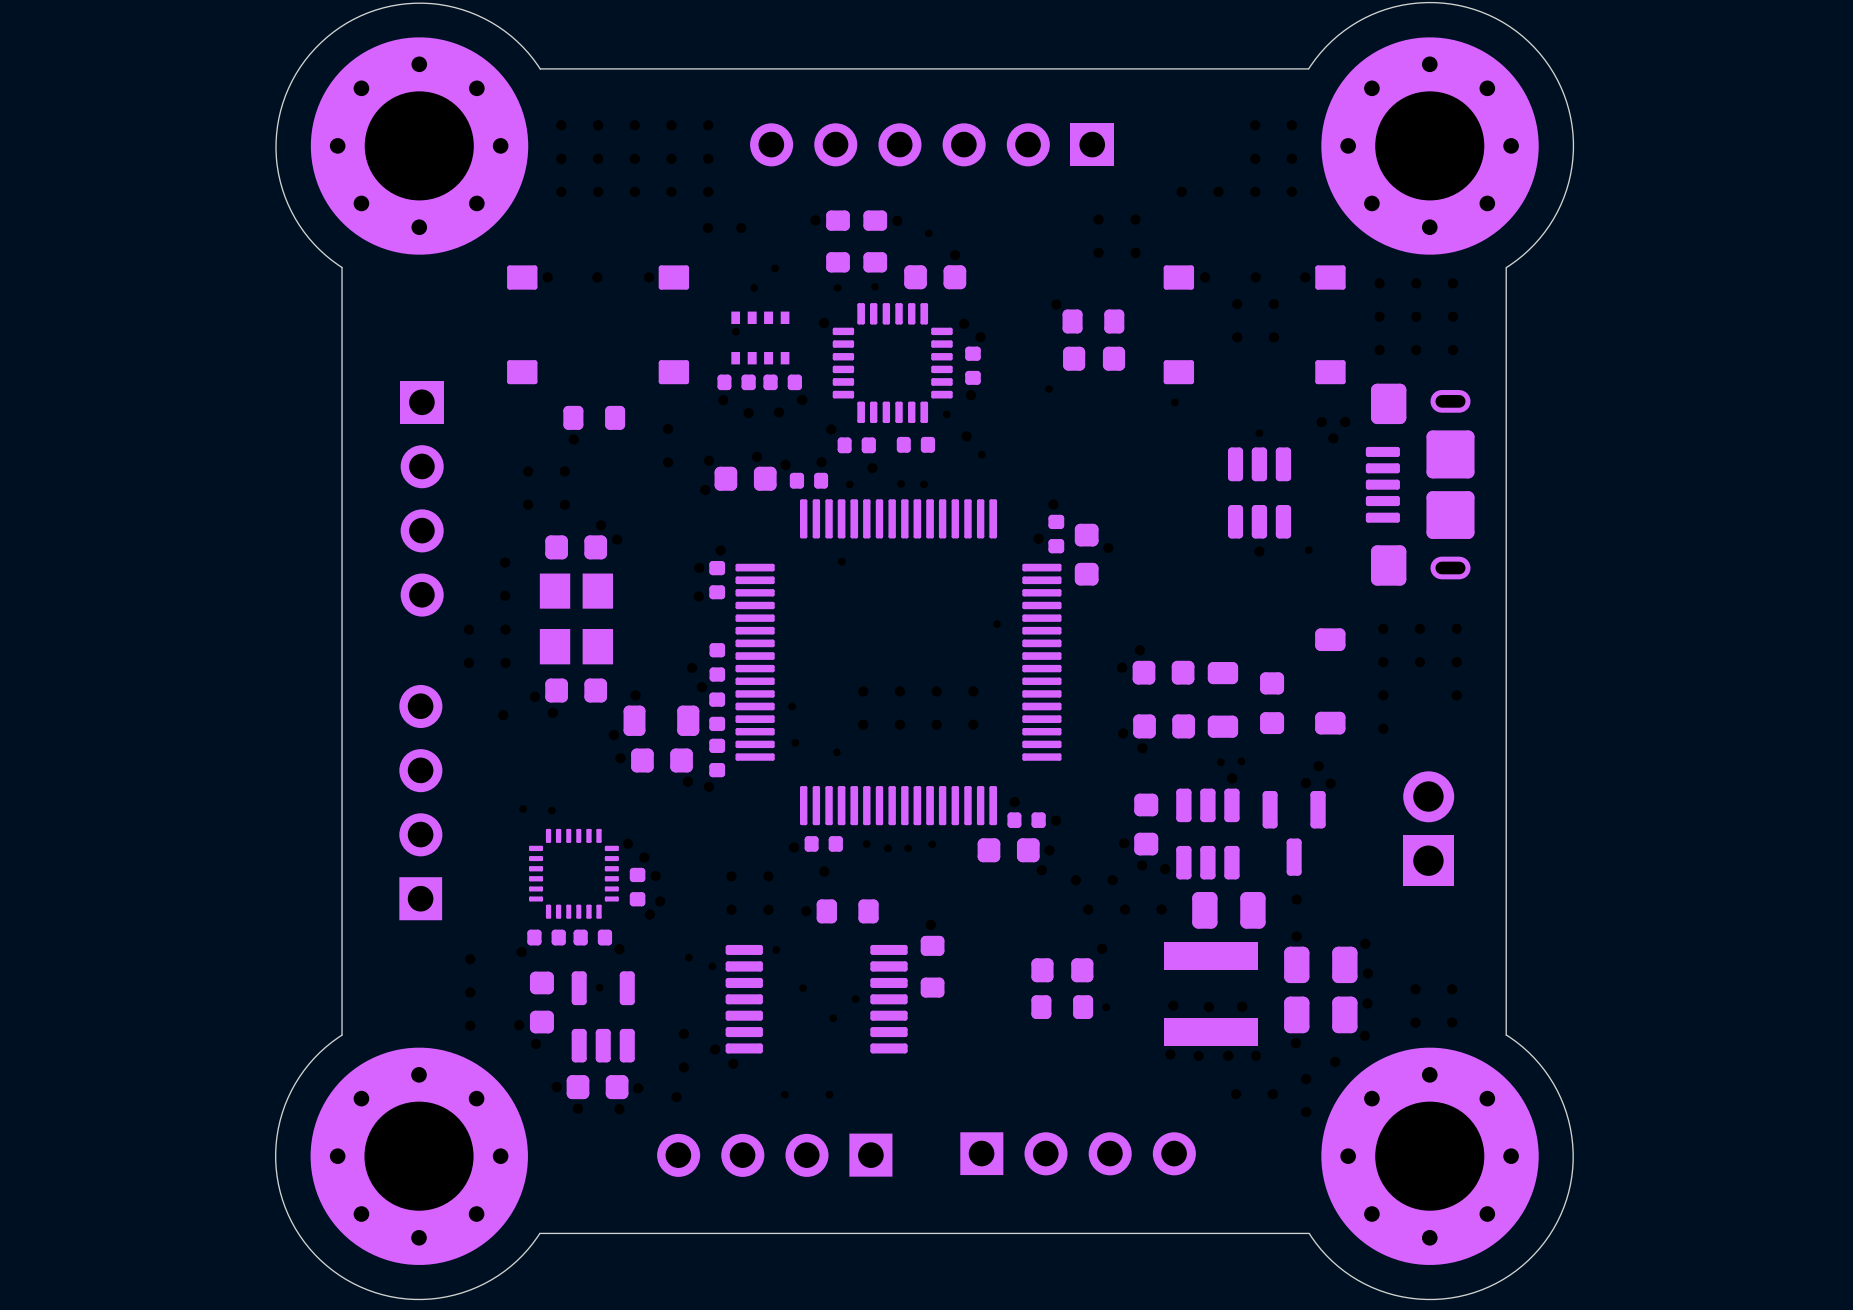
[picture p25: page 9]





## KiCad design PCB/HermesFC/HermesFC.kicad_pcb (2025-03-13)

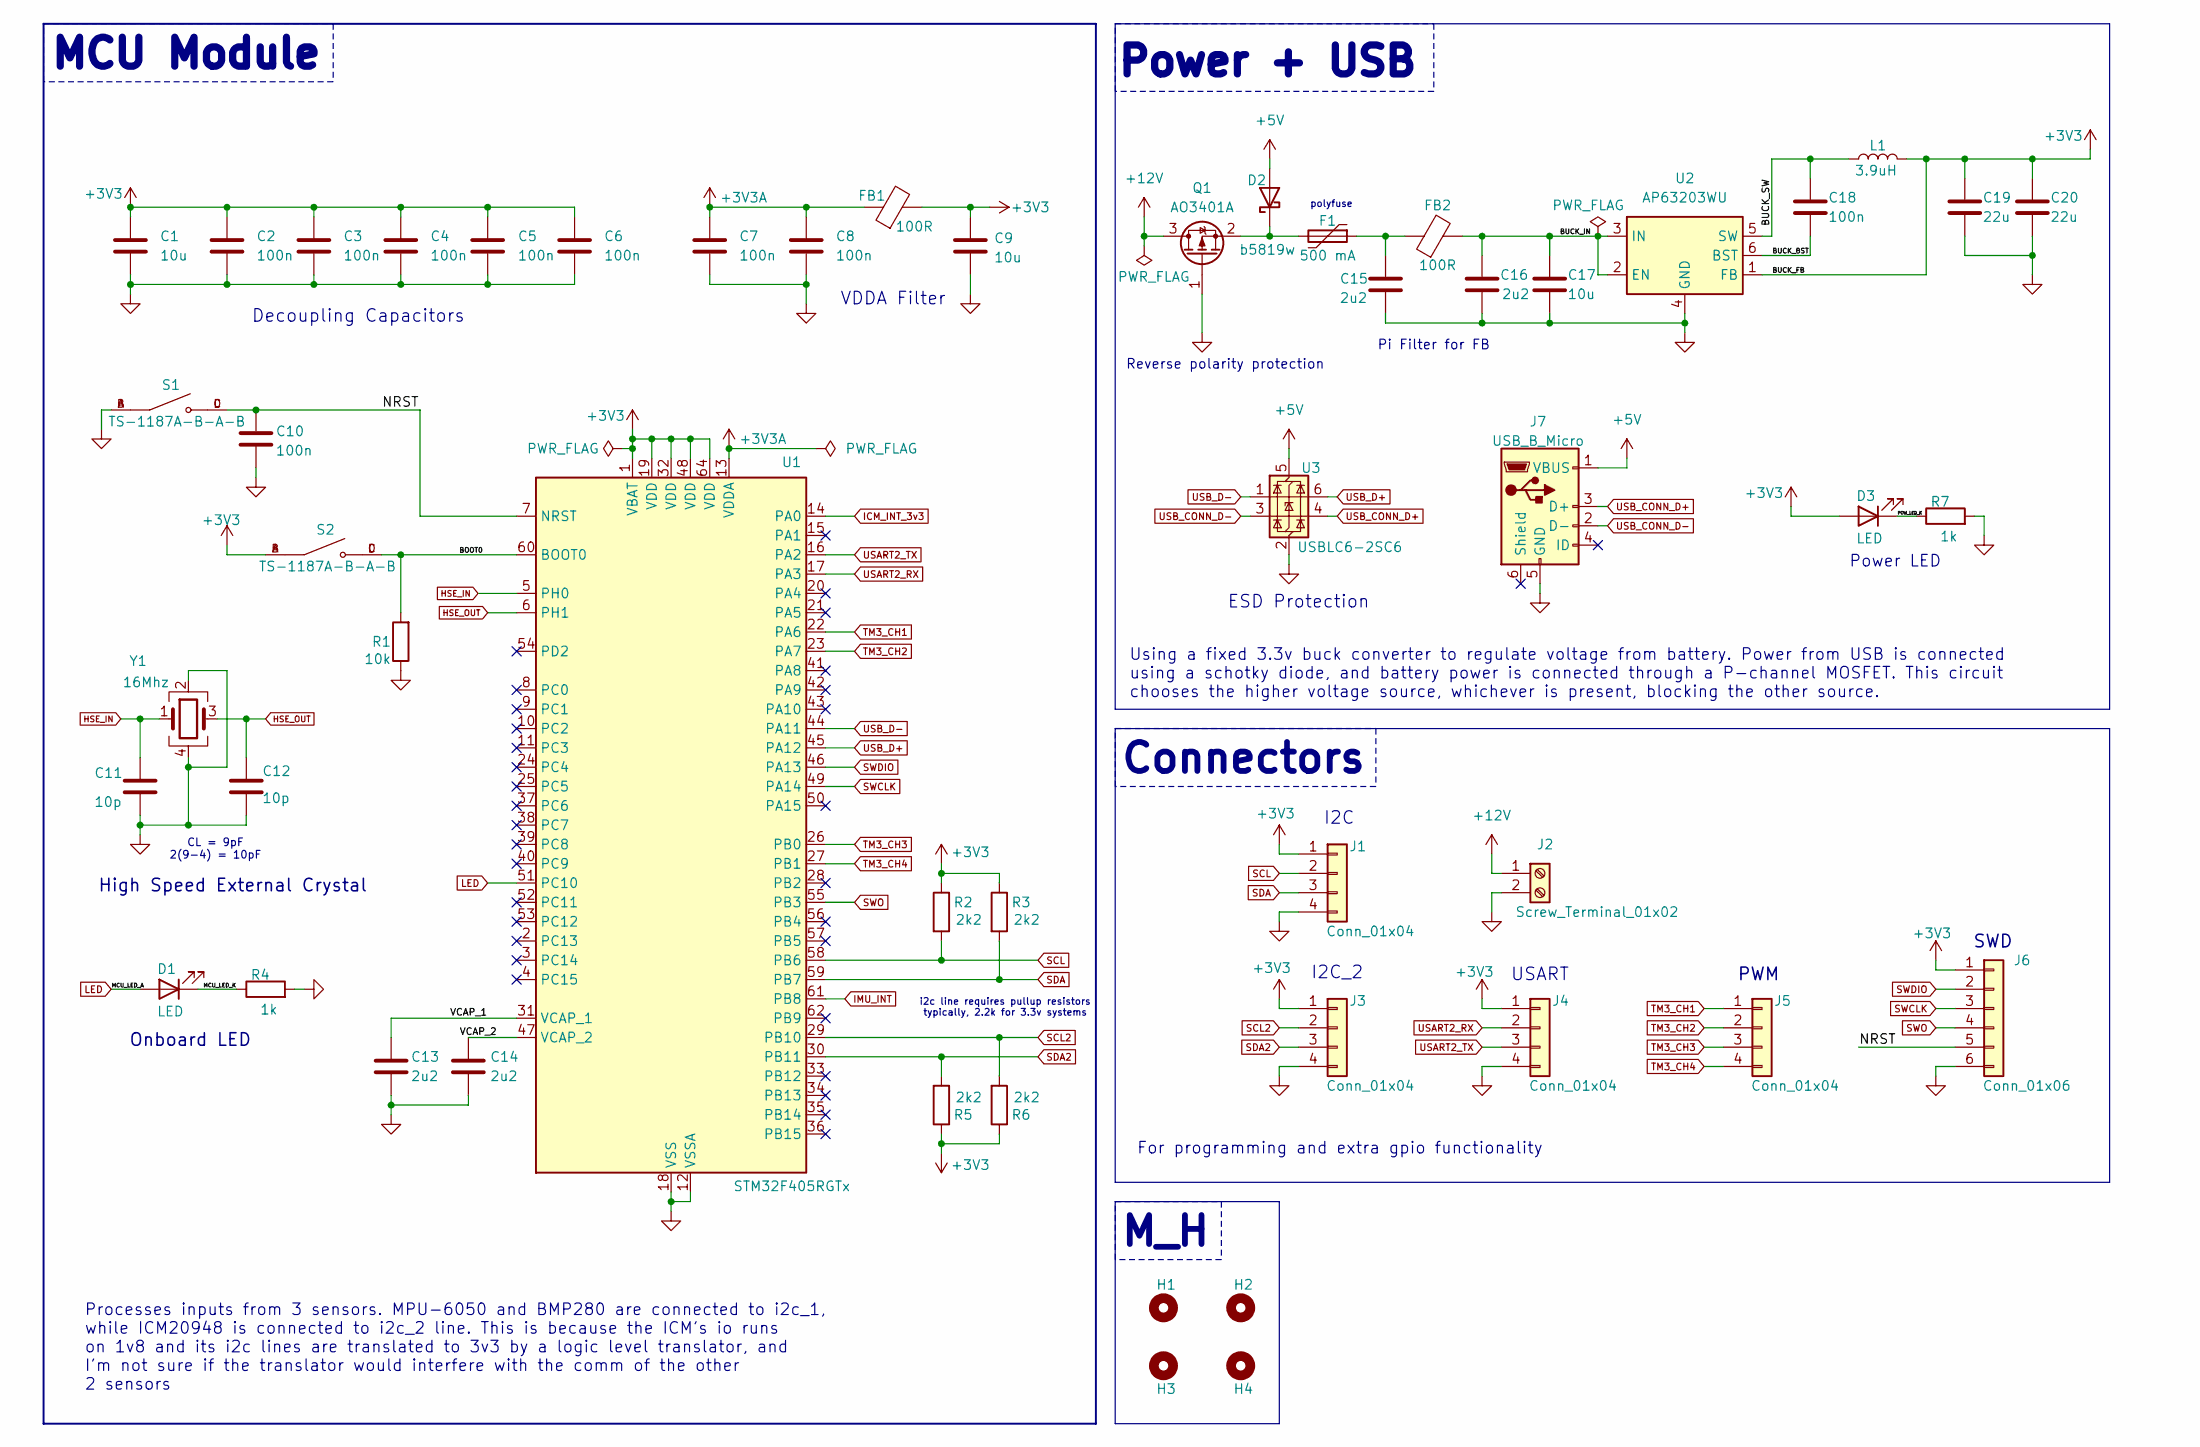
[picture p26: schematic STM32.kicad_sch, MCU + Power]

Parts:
C1, C9, C17: 10u; C_0603_1608Metric
C2, C3, C4, C5, C6, C7, C8, C10: 100n; C_0402_1005Metric
C11, C12: 10p; C_0603_1608Metric
C13, C14, C15, C16: 2u2; C_0603_1608Metric
C18: 100n; C_0805_2012Metric
C19, C20: 22u; C_0805_2012Metric
D1, D3: LED; LED_0603_1608Metric
D2: b5819w; D_SOD-123
F1: 500 mA; Fuse_0603_1608Metric
FB1, FB2: 100R; L_0805_2012Metric
H1, H2, H3, H4: MountingHole; MountingHole_4.3mm_M4_Pad_Via
J1, J3, J4, J5: Conn_01x04; PinSocket_1x04_P2.54mm_Vertical
J2: Screw_Terminal_01x02; TerminalBlock_Xinya_XY308-2.54-2P_1x02_P2.54mm_Horizontal
J6: Conn_01x06; PinSocket_1x06_P2.54mm_Vertical
J7: USB_B_Micro; USB_Micro-B_Amphenol_10118193-0001LF_Horizontal
L1: 3.9uH; L_Sunlord_SWPA4030S
Q1: AO3401A; SOT-23
R1: 10k; R_0603_1608Metric
R2, R3, R5, R6: 2k2; R_0603_1608Metric
R4, R7: 1k; R_0603_1608Metric
S1, S2: TS-1187A-B-A-B; SW_TS-1187A-B-A-B; PARTREV A0
U1: STM32F405RGTx; LQFP-64_10x10mm_P0.5mm
U2: AP63203WU; TSOT-23-6
U3: USBLC6-2SC6; SOT-23-6
Y1: 16Mhz; Crystal_SMD_3225-4Pin_3.2x2.5mm

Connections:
+3V3: C1.1, C2.1, C3.1, C4.1, C5.1, C6.1, C9.1, C19.1, C20.1, D3.2 (A), FB1.2, J1.1, J3.1, J4.1, J6.1, L1.2, R2.1, R3.1, R5.1, R6.1, S2.A, S2.B, U1.1 (VBAT), U1.19 (VDD), U1.32 (VDD), U1.48 (VDD), U1.64 (VDD), U2.1 (FB); also elsewhere on the board
+3V3A: C7.1, C8.1, FB1.1, U1.13 (VDDA)
+5V: D2.2 (A), J7.1 (VBUS), U3.5 (VBUS)
+12V: J2.1, Q1.3 (D)
/STM32/BOOT0: R1.2, S2.C, S2.D, U1.60 (BOOT0)
/STM32/BUCK_BST: C18.2, U2.6 (BST)
/STM32/BUCK_IN: C16.1, C17.1, FB2.2, U2.2 (EN), U2.3 (IN)
/STM32/BUCK_SW: C18.1, L1.1, U2.5 (SW)
/STM32/MCU_LED_K: D1.1 (K), R4.1
/STM32/NRST: C10.1, J6.5, S1.C, S1.D, U1.7 (NRST)
/STM32/POW_LED_K: D3.1 (K), R7.1
/STM32/VCAP_1: C13.1, U1.31 (VCAP_1)
/STM32/VCAP_2: C14.1, U1.47 (VCAP_2)
GND: C1.2, C2.2, C3.2, C4.2, C5.2, C6.2, C7.2, C8.2, C9.2, C10.2, C11.2, C12.2, C13.2, C14.2, C15.2, C16.2, C17.2, C19.2, C20.2, H1.1, H2.1, H3.1, H4.1, J1.4, J2.2, J3.4, J4.4, J6.6, J7.5 (GND), Q1.1 (G), R1.1, R4.2, R7.2, S1.A, S1.B, U1.12 (VSSA), U1.18 (VSS), U1.63 (VSS), U2.4 (GND), U3.2 (GND), Y1.2, Y1.4; also elsewhere on the board
HSE_IN: C11.1, U1.5 (PH0), Y1.1
HSE_OUT: C12.1, U1.6 (PH1), Y1.3
ICM_INT_3v3: U1.14 (PA0); also elsewhere on the board
IMU_INT: U1.61 (PB8); also elsewhere on the board
LED: D1.2 (A), U1.51 (PC10)
unnamed: C15.1, F1.1, FB2.1
unnamed: D2.1 (K), F1.2, Q1.2 (S)
SCL: J1.2, R2.2, U1.58 (PB6); also elsewhere on the board
SCL2: J3.2, R6.2, U1.29 (PB10); also elsewhere on the board
SDA: J1.3, R3.2, U1.59 (PB7); also elsewhere on the board
SDA2: J3.3, R5.2, U1.30 (PB11); also elsewhere on the board
SWCLK: J6.3, U1.49 (PA14)
SWDIO: J6.2, U1.46 (PA13)
SWO: J6.4, U1.55 (PB3)
TM3_CH1: J5.1, U1.22 (PA6)
TM3_CH2: J5.2, U1.23 (PA7)
TM3_CH3: J5.3, U1.26 (PB0)
TM3_CH4: J5.4, U1.27 (PB1)
USART2_RX: J4.2, U1.17 (PA3)
USART2_TX: J4.3, U1.16 (PA2)
USB_CONN_D+: J7.3 (D+), U3.4 (I/O2)
USB_CONN_D-: J7.2 (D-), U3.3 (I/O2)
USB_D+: U1.45 (PA12), U3.6 (I/O1)
USB_D-: U1.44 (PA11), U3.1 (I/O1)

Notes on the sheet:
polyfuse
ESD Protection
Decoupling Capacitors
CL = 9pF 2(9-4) = 10pF
Using a fixed 3.3v buck converter to regulate voltage from battery. Power from USB is connected using a schotky diode, and battery power is connected through a P-channel MOSFET. This circuit chooses the higher voltage source, whichever is present, blocking the other source.
VDDA Filter
Onboard LED
i2c line requires pullup resistors typically, 2.2k for 3.3v systems
USART
Processes inputs from 3 sensors. MPU-6050 and BMP280 are connected to i2c_1, while ICM20948 is connected to i2c_2 line. This is because the ICM's io runs on 1v8 and its i2c lines are translated to 3v3 by a logic level translator, and I'm not sure if the translator would interfere with the comm of t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
M_H
Pi Filter for FB
For programming and extra gpio functionality
I2C
SWD
High Speed External Crystal
Power LED
PWM
Reverse polarity protection
MCU Module
Connectors
Power + USB
I2C_2

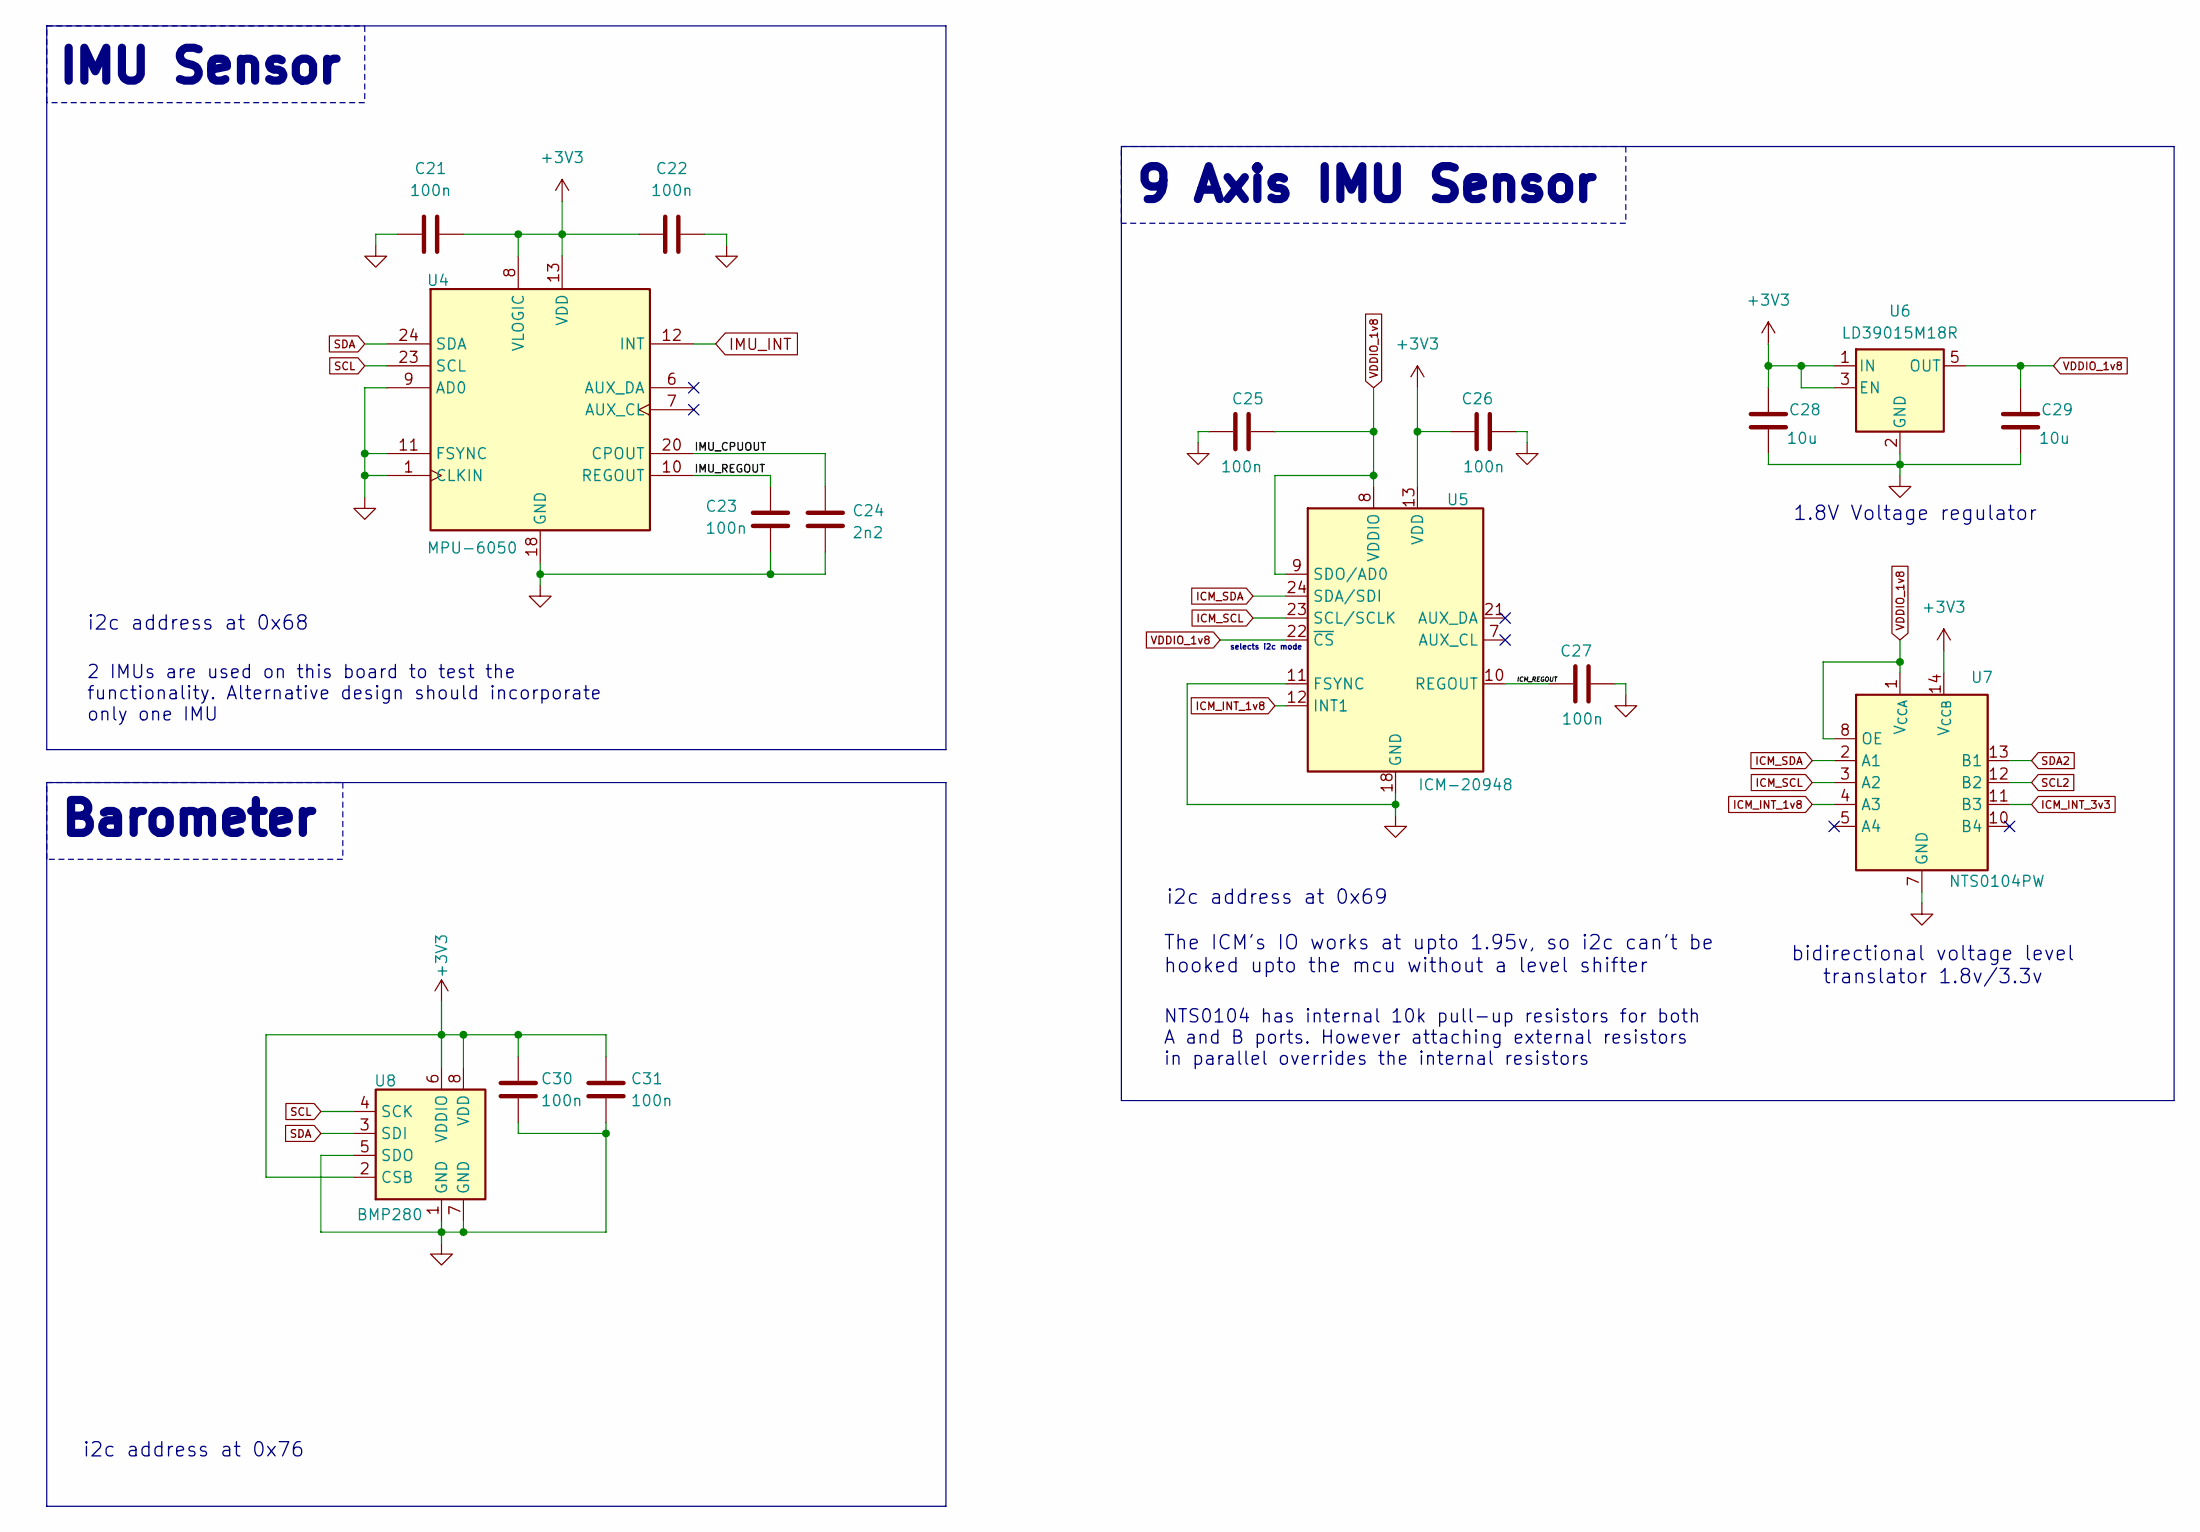
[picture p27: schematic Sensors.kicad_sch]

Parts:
C21, C22, C23, C25, C26, C27, C30, C31: 100n; C_0402_1005Metric
C24: 2n2; C_0603_1608Metric
C28, C29: 10u; C_0603_1608Metric
U4: MPU-6050; InvenSense_QFN-24_4x4mm_P0.5mm
U5: ICM-20948; InvenSense_QFN-24_3x3mm_P0.4mm
U6: LD39015M18R; SOT-23-5
U7: NTS0104PW; TSSOP-14_4.4x5mm_P0.65mm
U8: BMP280; Bosch_LGA-8_2x2.5mm_P0.65mm_ClockwisePinNumbering

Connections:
+3V3: C21.2, C22.1, C26.1, C28.1, C30.1, C31.2, U4.8 (VLOGIC), U4.13 (VDD), U5.13 (VDD), U6.1 (IN), U6.3 (EN), U7.14 (V_{CCB}), U8.2 (CSB), U8.6 (VDDIO), U8.8 (VDD); also elsewhere on the board
/Sensors/ICM_REGOUT: C27.1, U5.10 (REGOUT)
/Sensors/IMU_CPUOUT: C24.1, U4.20 (CPOUT)
/Sensors/IMU_REGOUT: C23.1, U4.10 (REGOUT)
GND: C21.1, C22.2, C23.2, C24.2, C25.2, C26.2, C27.2, C28.2, C29.2, C30.2, C31.1, U4.1 (CLKIN), U4.9 (AD0), U4.11 (FSYNC), U4.18 (GND), U5.11 (FSYNC), U5.18 (GND), U5.20 (GND), U6.2 (GND), U7.7 (GND), U8.1 (GND), U8.5 (SDO), U8.7 (GND); also elsewhere on the board
ICM_INT_1v8: U5.12 (INT1), U7.4 (A3)
ICM_INT_3v3: U7.11 (B3); also elsewhere on the board
ICM_SCL: U5.23 (SCL/SCLK), U7.3 (A2)
ICM_SDA: U5.24 (SDA/SDI), U7.2 (A1)
IMU_INT: U4.12 (INT); also elsewhere on the board
SCL: U4.23 (SCL), U8.4 (SCK); also elsewhere on the board
SCL2: U7.12 (B2); also elsewhere on the board
SDA: U4.24 (SDA), U8.3 (SDI); also elsewhere on the board
SDA2: U7.13 (B1); also elsewhere on the board
VDDIO_1v8: C25.1, C29.1, U5.8 (VDDIO), U5.9 (SDO/AD0), U5.22 (~CS), U6.5 (OUT), U7.1 (V_{CCA}), U7.8 (OE)

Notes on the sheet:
9 Axis IMU Sensor
i2c address at 0x76
1.8V Voltage regulator
2 IMUs are used on this board to test the functionality. Alternative design should incorporate only one IMU
NTS0104 has internal 10k pull-up resistors for both A and B ports. However attaching external resistors in parallel overrides the internal resistors
IMU Sensor
i2c address at 0x69
Barometer
i2c address at 0x68
selects i2c mode
bidirectional voltage level translator 1.8v/3.3v
The ICM's IO works at upto 1.95v, so i2c can't be hooked upto the mcu without a level shifter

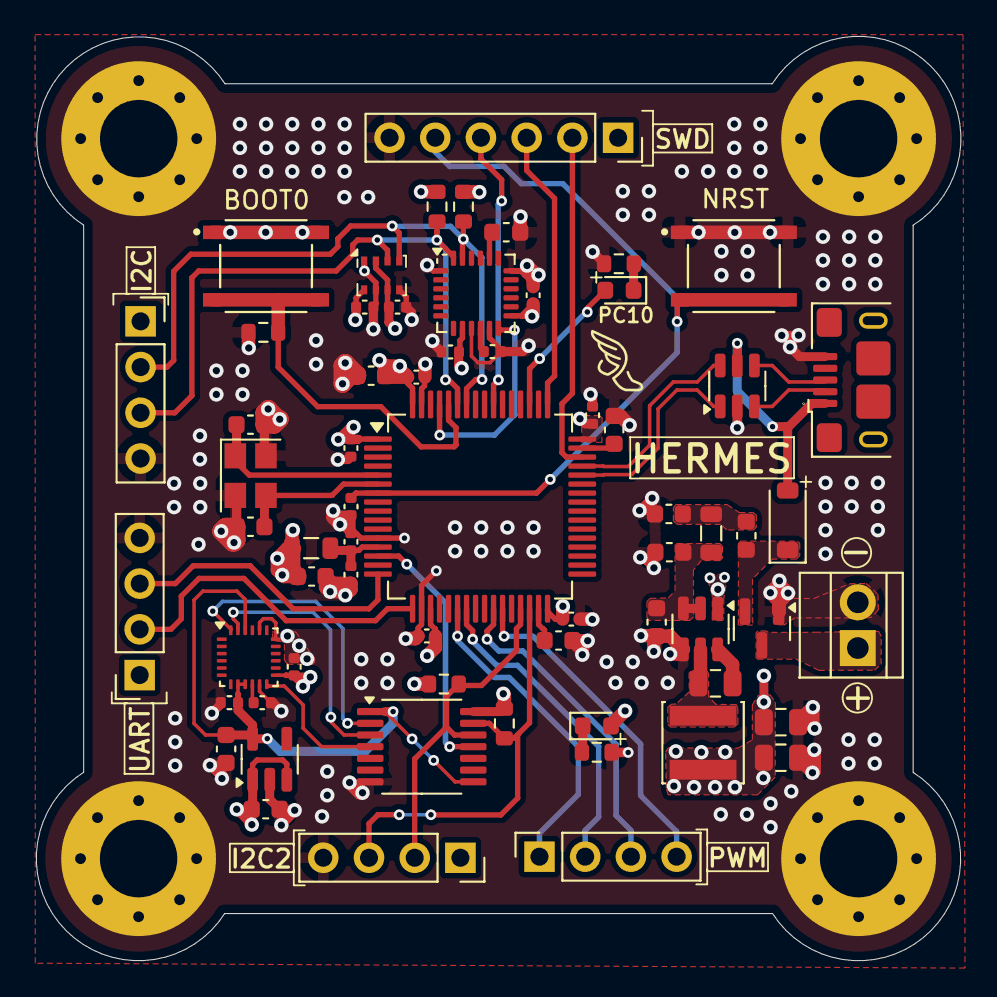
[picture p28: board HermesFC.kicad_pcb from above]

Board: 4 copper layers, 51.4 x 51.3 mm, 68 parts (0 on the bottom side), 45 nets.

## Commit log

2025-02-25 v0.1 schematic upload
    [HermesFC.kicad_pcb, HermesFC.kicad_sch, STM32.kicad_sch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]
2025-03-02 v0.2 updated schematic + PCB
    added battery power source to PCB
    [Hermes-FlightController.kicad_pcb, Hermes-FlightController.kicad_sch, ICM-20948.stp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]
2025-03-02 Schematic png
2025-03-10 Updated design files for optimized BOM
    [Hermes-FlightController.kicad_pcb, Hermes-FlightController.kicad_sch, HermesFC.kicad_pcb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]
2025-03-10 add gerber
2025-03-10 branch main design to create newer compact design
    [HermesFC.kicad_pcb]
2025-03-11 update design to be more compact
    [HermesFC.kicad_pcb, HermesFC.kicad_sch, STM32.kicad_sch]
2025-03-11 complete compact routing
    [HermesFC.kicad_pcb, STM32.kicad_sch]
2025-03-12 finalise silkscreen
    [HermesFC.kicad_pcb]
2025-03-12 new compact PCB design
    [HermesFC.kicad_sch, STM32.kicad_sch, Sensors.kicad_sch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]
2025-03-12 minor changes C18
    [HermesFC.kicad_pcb, STM32.kicad_sch, bom.csv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]
2025-03-13 stitching between ground planes
    [HermesFC.kicad_pcb, positions.csv]
